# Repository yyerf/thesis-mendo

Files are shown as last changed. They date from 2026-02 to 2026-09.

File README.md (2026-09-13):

# Mendo

Mendo is a multilingual, knowledge-based expert system for OTC consultation and
medicine vending. It combines deterministic English/Tagalog/Cebuano phrase and
safety rules with the pretrained
`sentence-transformers/paraphrase-multilingual-MiniLM-L12-v2` embedding model.
MiniLM cosine similarity supports phrase interpretation; it is not a trained
clinical classifier and its scores are not probabilities.

## Run locally

Python 3.10+ is recommended.

```bash
python3 -m venv .venv
source .venv/bin/activate
pip install -r requirements.txt
python3 app.py
```

Open `http://localhost:5000`. On first run, Mendo creates
`data/mendo_pos.db`, applies additive migrations, seeds the inventory, and
downloads MiniLM if it is not already cached. The runtime database, journals,
application logs, and raw consultation logs are intentionally ignored by Git.

The seeded administrator is for first-run development only:

- Username: `admin`
- Password: `mendo2026`

Change the password immediately in any shared or deployed environment, and set
`MENDO_SECRET_KEY` to a stable secret.

## Hardware integration status

The current build is intentionally **payment-only**. The tested Allan D2 coin
path and TB74 D3 bill path are integrated with the Cashier and kiosk checkout
screens. A successful payment creates one receipt and deducts reserved stock
exactly once. Medicine motors are compile-time disabled: no paid checkout can
send a servo/rotor command in this phase.

The real controller runs at 115200 baud through the dedicated hardware daemon.
Simulator cash remains visibly labelled for software-only tests. This is a
prototype test gate, not production authorization; wiring, voltage, enclosure,
cashbox, restart-replay, and long-run acceptance evidence still require
completion. See the [hardware guide](hardware/README.md) and
[CHECKPOINT.md](CHECKPOINT.md) before connecting an Arduino.

## Ten-slot medicine catalog

Production recommendations, POS inventory, checkout, and benchmarks use one
versioned hardware catalog:
`mendo-hardware-catalog-v1-2026-07`. The formulation-level JSON remains the
reference source, but runtime loading selects exactly these ten physical items:

| Slot | Medicine | Runtime category | Form | Minimum age |
|---:|---|---|---|---:|
| 1 | Advil | Pain & Inflammation | Tablet | 12 |
| 2 | Bioflu | Cold & Flu | Tablet | 12 |
| 3 | Biogesic | Pain & Fever | Tablet | 12 |
| 4 | Cetirizine | Allergy | Tablet | 6 |
| 5 | Solmux | Cough with Phlegm / Productive Cough | Capsule | 12 |
| 6 | Tuseran | Dry Cough | Tablet | 12 |
| 7 | Symdex | Cold & Cough | Tablet | 6 |
| 8 | Neozep | Cold | Tablet | 6 |
| 9 | Loperamide | Anti-diarrhea | Tablet | 6 |
| 10 | Erceflora | Probiotic (Adjunct for Diarrhea) | Oral Suspension | All ages |

Startup migrations rename older aliases without changing inventory IDs, assign
hardware slots, and mark products outside the catalog inactive. Historical
transactions and stock movements are never deleted. Erceflora is treated only
as an adjunct; food-poisoning guidance still requires oral rehydration and
excludes loperamide.

## Consultation and audit flow

1. The participant accepts or declines multilingual research consent.
2. Dictionary rules record matched, negated, and safety-suppressed evidence.
3. MiniLM records its model id, anchors, threshold, and cosine similarities.
4. Expert rules resolve symptom labels, red flags, severity, duration,
   clarification, age, headache illustration, and recommendation filtering.
5. Consented consultations are stored as session timelines for independent
   domain-expert review.
6. An administrator adjudicates disagreements into a final gold annotation.
7. Only consented and adjudicated records enter research exports or field
   validation metrics. Nothing automatically retrains production.

Declining consent does not block consultation. Raw health text is not persisted;
only an anonymous aggregate operational counter is incremented. The 507
pre-consent interactions retained during merge recovery are marked
legacy/unconsented and excluded from research exports and field metrics.

## Evaluation terminology

- **Synthetic technical benchmark**: researcher/LLM-created regression cases in
  `testing/benchmark/testing.csv`. This is technical evidence, not clinical
  field validation.
- **Domain-expert field validation**: independently reviewed, consented
  consultations with administrator-adjudicated gold labels.
- **Per-case precision, recall, F1, and exact match**: computed only after
  adjudication.
- **Micro F1**: pools label decisions across all eligible cases.
- **Macro F1**: averages performance across labels.
- **Cohen’s kappa**: shown only when at least two reviewers share reviewed
  cases; otherwise the interface reports “insufficient reviewers.”
- **Clinical appropriateness**: the proportion of adjudicated recommendation
  judgments marked appropriate among appropriate/inappropriate judgments.

Run verification:

```bash
python3 -m unittest discover -s testing -p 'test_*.py' -v
python3 testing/test_algorithm.py
```

The benchmark script uses the same `predict_symptoms` service as
`/consult/api/analyze`, reports both raw-input and guided-clarification metrics,
and writes the single tracked manifest at
`testing/benchmark/results/current.json`. Timestamped HTML/CSV runs are ignored.

## Repository map

- `mendo_core/prediction_pipeline.py` — deployed, versioned prediction service
- `mendo_core/medicine_catalog.py` — canonical hardware-slot allowlist and aliases
- `mendo_core/interaction_logger.py` — consent, audit, reviews, adjudication,
  metrics, and de-identified exports
- `pos/routes_consultation.py` — consultation APIs
- `pos/routes_admin.py` — restricted clinical audit APIs
- `web/templates/pos/logs.html` — session-oriented reviewer interface
- `testing/benchmark/results/current.json` — current synthetic benchmark manifest
- `docs/thesis/current/` — canonical thesis and synchronized comments document
- `docs/thesis/archive/` — prior DOCX/PDF revisions retained in history
- `docs/research/` — research audits and diagrams
- `docs/defense/` — defense notes and presentation material

The ignored `_For-Mendo/` five-brand SVM prototype is not a production
dependency and is not imported by the application.

See [docs/README.md](docs/README.md) for the document index.

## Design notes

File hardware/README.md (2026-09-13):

# MendoVendo hardware guide

Status: **payment-only POS integration enabled for the measured D2/D3 pulse paths; medicine motors disabled**

The controller now carries the same D2 coin and D3 TB74 timing filters used by
the successful bench sketch. The host maps validated pulses, binds them to one
active payment session, persists them before ACK, and retains every queued
event in a burst. When the amount due is reached, inventory and the receipt are
committed atomically. `DISPENSE_ONE` remains rejected at the firmware boundary,
and PCA9685 OE is held HIGH (disabled).

This enables the requested supervised POS payment test. It does not establish
production readiness: keep medicine motors disconnected, keep the collection
box supervised, and retain the simulator label as the software-only fallback.
The supplied legacy sketches remain under [`references/legacy/`](references/legacy/)
and are not the integrated controller.

## Run a payment-only test

1. Open `hardware/firmware/mendo_controller/mendo_controller.ino` in Arduino
   IDE, select Arduino Uno, and upload it. Close Serial Monitor afterward; the
   daemon needs exclusive access at **115200 baud**.
2. Start the hardware daemon (replace `/dev/ttyACM0` if the Uno has another
   stable path):

   ```bash
   MENDO_HARDWARE_MODE=real \
   MENDO_HARDWARE_SOCKET=/tmp/mendo-hardware.sock \
   MENDO_SERIAL_DEVICE=/dev/ttyACM0 \
   ./.venv/bin/python -m hardware.daemon_main
   ```

3. In a second terminal, start the POS against the same socket:

   ```bash
   MENDO_HARDWARE_MODE=real \
   MENDO_HARDWARE_SOCKET=/tmp/mendo-hardware.sock \
   ./.venv/bin/python app.py
   ```

4. Open `/shop`, add medicine, select **Start Cash Payment**, and insert cash.
   The live dialog shows due, inserted, and remaining values. On success, verify
   `/admin/inventory`, the receipt, and stock logs. No motor job should exist.

## Reference files

Tracked copies and provenance are listed in
[`hardware/references/README.md`](references/README.md). The original supplied
files remain at the repository root while this integration is being audited.

The TB-to-Uno bench wiring is documented in the
[editable wiring diagram](tb-arduino-uno-wiring.svg) and its
[connection guide](tb-arduino-uno-wiring.md). Neither authorizes physical
power-up; the Phase-0 identity, polarity, voltage, and pulse-evidence gate
must be cleared first.

## Locked hardware mapping

| Arduino connection | Function |
| --- | --- |
| D0/D1 | USB serial only; no peripherals |
| D2 / INT0 | conditioned Allan coin pulse input |
| D3 / INT1 | conditioned TB METER pulse input |
| D4 | TB inhibit transistor control |
| D5 | fail-off coin-acceptor power relay/load switch |
| D6 | reserved for future shared chute sensor |
| D7 | PCA9685 active-low OE safety control |
| D8 | reserved enclosure/interlock input |
| A4/A5 | PCA9685 SDA/SCL |
| PCA channels 0–9 | hardware slots 1–10 |

Uno and Mega builds must share one source tree. Board selection is a
compile-time target detail only; slot numbering, protocol frames, and database
mapping do not change.

## Power and safety gate

- Power the Arduino from host USB. Never put the acceptor’s 12 V rail on an
  Arduino input.
- Use a separately fused regulated 12 V supply for the TB and Allan devices.
  The TB guide states 12 V DC ±10%, with up to 1.2 A maximum operation.
- Use the external fused 5 V servo supply for the PCA9685 servo rail. Never
  power an MG996R from the Uno 5 V pin. Only one servo may be active at a time.
- Tie Arduino ground, PCA9685 logic ground, and servo-supply ground together
  at the documented logic boundary; keep the 12 V cash-device side isolated
  through the optocoupler/load-control interfaces.
- A hardware pull-up on PCA9685 OE must leave outputs disabled during reset,
  boot, serial loss, and firmware failure.
- Fit a master disconnect, branch fuses sized from measured current, terminal
  blocks, strain relief, and a locked collection enclosure.
- Before attaching the Uno, perform continuity and voltage tests. Every
  conditioned Arduino-side signal must measure 0–5 V in all expected states.

## TB bill acceptor bench wiring

The supplied guide documents WEL-R7U02 as follows. Verify every conductor with
continuity; do not trust color alone.

| Harness color | Function |
| --- | --- |
| Red | +12 V DC |
| Orange | 12 V ground |
| Blue | METER+ |
| Purple | METER- |
| Yellow | INHIBIT+ |
| Green | INHIBIT- |

Use the manual’s isolated customer-side pulse circuit: 4.7 kΩ pull-up to
Arduino 5 V, METER+ to D3, and METER- to Arduino logic ground. Drive the
inhibit pair through the documented NPN interface with a base resistor and
hardware pull-down. Select and prove a polarity where boot, reset, missing
heartbeat, disconnected USB, and daemon failure inhibit the acceptor.

The exact TB model (TB74/TB77 variant), PHP firmware label, DIP banks, currency
sheet, pulse protocol, and pulse counts are **not yet recorded**. Do not copy
settings from a TP-series Philippine sheet. Record twenty consecutive correct
trials for each enabled ₱20/₱50/₱100 denomination and rejection trials for
₱200/₱500/₱1000 before enabling cash.

## Allan coin acceptor bench calibration

Use a 12 V-rated optocoupler input module. The unknown-voltage COIN wire must
not connect directly to D2. The optocoupler’s 5 V-side collector connects to
D2 with an external pull-up. Control acceptor power through the fail-off relay
or rated high-side load switch on D5 so an inactive order cannot swallow a
coin.

The selected six programs are:

| Program | Coin sample | H | P | F |
| --- | --- | ---: | ---: | ---: |
| 1 | old/current ₱1 | 20 | 1 | 8 |
| 2 | other ₱1 variant | 20 | 1 | 8 |
| 3 | old/current ₱5 | 20 | 5 | 8 |
| 4 | other ₱5 variant | 20 | 5 | 8 |
| 5 | old/current ₱10 | 20 | 10 | 8 |
| 6 | other ₱10 variant | 20 | 10 | 8 |

Use actual circulating coins in acceptable condition. Start at medium pulse
speed. For each accepted sample, capture pulse width, inter-pulse gap, total
train duration, idle level, and the conditioned D2 voltage. Firmware constants
must be derived from those captures. Unknown trains disable both acceptors and
route the order to manual review.

## Servo and rotor safety

PCA channels 0–9 map to slots 1–10. Each persisted profile must include
`position_a_us`, `position_b_us`, travel time, B dwell, return settle, cooldown,
and profile version. Pulse widths must be calibrated and range-checked; do not
assume 0°/180° endpoints. A `DISPENSE_ONE` job executes A → B → A, disables
the channel’s PWM, and reports only `dispensed_done_unverified` until the
future shared chute sensor is installed.

Phase 4 evidence must include 100 unloaded cycles and 20 loaded trials per
slot, with current draw, voltage droop, resets, jams, and wear recorded. A
successful servo acknowledgment is not evidence that medicine physically
reached the customer.

## Phase 0 evidence worksheet

Complete this table from the physical bench and attach photos or capture files
under `hardware/evidence/` (do not commit secrets or customer data).

| Evidence | Result | File/photo/capture |
| --- | --- | --- |
| TB exact model and variant | TB74-PH60Ni (label TB7441123 / 10PH6003 / B444) | operator-reported |
| TB PHP firmware label | PH6 — ₱20/50/100/200/500/1000 | vendor sheets in `references/vendor-dip-sheets/` |
| TB harness continuity | **pending** | pending |
| TB DIP banks and inhibit polarity | Pulse mode, 1 pulse/₱10, Fast, inhibit Active High; SW6+SW7 enable ₱20/₱50/₱100 | `docs/architecture/tb74-pulse-protocol-analysis.md` §1b |
| TB ₱20 pulse count/width/gap | **2 pulses**, 50 ms LOW, 151 ms period | 2026-08-03 23:23:16 capture |
| TB ₱50 pulse count/width/gap | **5 pulses**, 50 ms LOW, 150 ms period | 2026-08-03 23:23:21 capture |
| TB ₱100 pulse count/width/gap | **10 pulses**, 50 ms LOW, 150 ms period | 2026-08-03 23:23:24 capture |
| Higher-bill rejection | **pending** — ₱200/₱500/₱1000 disabled at DIP, not yet trialled | pending |
| Rejected-note zero-credit | 6 rejections, 23,064 raw edges, ₱0 credited | 2026-08-03 23:23 capture |
| Allan coin pulse captures | **pending** | pending |
| Arduino-side D2/D3 levels | **pending** | pending |
| 12 V and servo-rail measurements | **pending** | pending |
| Hardware photos | **pending** | pending |

Until every required row has evidence, the production gate remains closed.

## Software-only integration

The durable workflow lives in `pos/order_service.py`. It reserves stock using
`stock_quantity - reserved_quantity`, records integer-centavo payment events
exactly once, creates one immutable dispense job per unit, and projects one
legacy receipt only after every actuator job is acknowledged as
`done_unverified`. A successful controller motion is never presented as proof
that medicine reached the chute.

After a Flask restart, polling a paid order resumes the durable dispatcher. It
queries any `started` job by immutable controller ID before sending another
command. Only a controller-negative `known=0` answer can release a job for a
staff retry; a missing or ambiguous answer remains manual review.

The hardware boundary is split into three processes/roles:

- `hardware.simulator.SimulatedHardware` is the deterministic development
  backend. Its status always says `mode=simulator` and
  `physical_evidence_required=true`.
- `hardware.daemon` owns the Unix socket and, in real deployments, the only
  serial descriptor. Flask workers use `UnixHardwareClient`; they never open a
  TTY. The sample systemd unit runs the daemon as `mendo-hardware:dialout`.
- `hardware.real_backend.SerialHardwareBackend` performs the bounded CRC
  handshake and heartbeat when the daemon is explicitly started in real mode.
  The firmware and service still require the physical-evidence/configuration
  gate to be cleared before cash can start.

Development commands:

```text
./.venv/bin/python -m pytest -q
MENDO_HARDWARE_MODE=simulator ./.venv/bin/python -m hardware.daemon_main
```

Do not set `MENDO_HARDWARE_MODE=real` until the Phase-0 worksheet is complete
and the R1–R4 remediation checkpoints have been approved. The current daemon
and firmware sources are not a release authorization for powered hardware.
The sample udev rule grants access to the dedicated daemon identity through
`dialout`; it does not recommend `chmod 666`.

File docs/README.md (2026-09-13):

# Thesis and research document index

## Current thesis

- `thesis/current/Latest-July-26-Thesis-Paper.docx` — canonical thesis paper
- `thesis/current/Thesis (Comments_Suggestions) - Synced.docx` — synchronized
  routing/comments companion

The paper files were reorganized only. Their prose was not silently rewritten.

## Archive

`thesis/archive/` contains previous DOCX/PDF revisions. Git history is retained,
but these files are not the current thesis source.

## Research material

- `architecture/cash-order-integration.md` — current durable order, hardware
  daemon, accounting, and recovery boundary
- `research/audits/` — architecture reviews, benchmark verification,
  methodology notes, and implementation proposals
- `research/diagrams/` — conceptual-framework HTML diagrams
- `../experiments/` — reproducible classifier/retrieval experiment code

Historical analyses may describe superseded behavior. The deployed architecture
and current terminology are defined by the repository README, the versioned
prediction trace, and the current benchmark manifest.

## Defense material

`defense/` contains checklists, mock-defense questions, demo notes, prompts, and
presentation drafts.

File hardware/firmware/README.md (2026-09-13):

# Uno/Mega controller firmware

`mendo_controller.ino` is the payment-only controller for the tested D2 coin
and D3 TB74 pulse paths. It is a single Arduino IDE sketch and also shares Uno
and Mega build definitions through `platformio.ini`:

```text
pio run -d hardware/firmware -e uno
pio run -d hardware/firmware -e mega
```

The cash gate is enabled from the completed pulse trials. Firmware reports
validated counts only; the Python host owns the peso mapping. The Uno build is
verified at 10,526 bytes flash and 1,407 bytes globals (641 bytes free), and frame transmission
streams its CRC instead of allocating a second large buffer on the stack.

Medicine motion is a separate gate and remains disabled. `DISPENSE_ONE` is
always rejected, PCA9685 OE is HIGH during boot/fail-safe/payment, and the
placeholder motion profiles must not be treated as calibration. Keep servos
disconnected during this phase. Cash-event replay after a daemon/controller
restart still needs a supervised fault test before production use.

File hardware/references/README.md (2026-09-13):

# Hardware reference provenance

These files are tracked copies of the user-supplied reference assets. The
original files remain at the repository root so their provenance is not lost.

| Tracked asset | Source asset | SHA-256 |
| --- | --- | --- |
| `allan-coinslot-calibration.pdf` | `allan coinslot calibration.pdf` | `f61b90333173e95069c2289ed1c668c82da0534886f46532962bb72f7905f08b` |
| `tb-series-installation-guide.pdf` | `tb_series.pdf` | `e76750a452e1b8256df684c881cd9940aa46bf6f3ee66b8e4ce60f6dc296d407` |
| `rotor_9pocket_35x20_recommended_clearance.stl` | `rotor_9pocket_35x20_recommended_clearance.stl` | `00e499be5a23a621b7a459fb6b675dc161f6a2a7e32c4f136401d9f087d7f9a8` |

The TB PDF is a generic TB-Series installation guide. It is not the missing
Philippine currency/DIP sheet and must not be used to infer PHP bill settings.

## Vendor DIP sheets

`vendor-dip-sheets/` holds manufacturer DIP-switch sheets retrieved for sibling
currency builds, including a genuine TOPVME **TB74** sheet on the same 10-way +
4-way bank layout as our unit, and two **PHP6** currency sheets. See
[`vendor-dip-sheets/README.md`](vendor-dip-sheets/README.md) for provenance and
the analysis in
[`docs/architecture/tb74-pulse-protocol-analysis.md`](../../docs/architecture/tb74-pulse-protocol-analysis.md).
These are still not the Philippine sheet for our exact unit; they narrow the
Phase-0 bench trial, they do not replace it.

## Legacy evidence

`legacy/Bill_Acceptor.ino` is the supplied V1 bill sketch. It is retained for
audit/provenance only and is not an approved controller source. Its 1-pulse =
₱10 mapping is an unverified starting hypothesis; do not flash it or use its
timing constants as calibration evidence.

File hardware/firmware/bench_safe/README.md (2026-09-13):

# USB-only bench diagnostic

`bench_safe.ino` is a temporary diagnostic image for board identification and
serial testing while the cash acceptors, PCA9685, and servos are disconnected.
It does not capture cash, drive the TB inhibit pair, access I2C, or move a
servo. It holds coin power off and PCA9685 OE high (disabled).

This is not the integrated controller and is not a cash-acceptance test.

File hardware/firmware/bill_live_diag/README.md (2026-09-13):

# Live bench diagnostics

Two read-only Arduino Uno sketches. Neither drives inhibit, coin power,
PCA9685 OE, or a servo. Neither can credit an order. They are bench
instruments; the Phase-0 gate in `hardware/README.md` still governs.

## `bill_live_diag` — is this a credit pulse or noise?

Watches **both** D2/INT0 and D3/INT1, so it works regardless of which pin
METER+ landed on. For every burst of line activity it prints raw edge count
next to clean pulse count:

- **raw edges** — unfiltered interrupt count, i.e. the noise floor
- **clean pulses** — survivors of a 20 ms glitch filter, i.e. real credit

The gap between those two numbers is the whole diagnosis. `raw=4000,
clean=0` means the line is busy but nothing was ever paid.

It also reports LOW width, pulse period, whether the timing matches TB74 Fast
(50/100) or Slow (50/300), and maps clean pulse counts to pesos at the
documented 1 pulse = ₱10 scaling:

| pulses | 2 | 5 | 10 | 20 | 50 | 100 |
| --- | --- | --- | --- | --- | --- | --- |
| value | ₱20 | ₱50 | ₱100 | ₱200 | ₱500 | ₱1000 |

Any interval under 80 ms is counted separately as `sub-80ms events` — the
fastest credit pulse in this whole device family is 80 ms, so those are
provably not payment.

## `line_check` — what is physically attached to this pin?

Samples D2 and D3 with the internal pull-up ON and OFF and reports duty
cycle, transition count and rate. That separates:

| Result | Meaning |
| --- | --- |
| `HELD LOW` | low-impedance path to GND — the pull-up cannot lift it. An idle METER+ reads HIGH, so this pin is **not** METER+ |
| `HIGH and quiet` | idle METER+ (correct), or an open pin — insert a note to tell them apart |
| `FLOATING` | nothing driving it |
| `OSCILLATING` | active noise source, unusable as-is |

## Running them

```bash
# build + flash
arduino --upload --board arduino:avr:uno --port /dev/ttyACM0 \
  hardware/firmware/bill_live_diag/bill_live_diag.ino

# watch (Ctrl-] to quit)
python3 -m serial.tools.miniterm /dev/ttyACM0 115200
```

Serial is **115200**. If you use the Arduino IDE's Serial Monitor instead,
set the baud rate to match or you will see garbage.

`USE_INTERNAL_PULLUP` at the top of `bill_live_diag.ino` defaults to `1` so
the sketch runs on the existing wiring. Set it to `0` once the external
4.7 kΩ pull-up to Uno 5 V is fitted — that is the value the TB manual's pulse
interface actually specifies (printed page 13 / PDF page 16).

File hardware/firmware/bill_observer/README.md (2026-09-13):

# TB bill-only observer

`bill_observer.ino` is an observe-only Arduino Uno sketch for the TB
WEL-R7U02 METER output. It captures `CHANGE` edges on D3/INT1 and prints raw
pulse count, every edge timestamp, pulse width, inter-pulse gap, train
duration, and the unverified V1 candidate mapping:

- 2 pulses → candidate ₱20.00
- 5 pulses → candidate ₱50.00
- 10 pulses → candidate ₱100.00

The mapping and 250 ms train gap are hypotheses only. The sketch never credits
an order, drives D4/TB inhibit, powers a coin acceptor, accesses the PCA9685,
or moves a servo.

Serial is 115200 baud. Send `ARM` before a pulse trial; use `STATUS`, `HELP`,
or `DISARM` as needed. Keep the TB inhibit pair disconnected from the Uno
until the exact TB PHP/DIP polarity has been measured. This is not a
production cash controller.

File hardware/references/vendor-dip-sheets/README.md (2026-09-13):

# Vendor DIP-switch sheets (external evidence)

Downloaded 2026-08-03 while reverse-engineering the TB74-PH6 pulse interface.
These are **manufacturer documents for sibling currency builds**, not the
missing Philippine sheet for our exact unit. They are strong structural
evidence and they agree with each other, but the Phase-0 bench trial is still
what promotes any value here to "measured".

| File | Source URL | What it establishes |
| --- | --- | --- |
| `TB74-DipSetting-Mexico-MXP6-20-1K-RS232-104U.pdf` | `topvme.com/index.php/files/330/Currencies-accepted-and-DipSetting/417/` | **Primary.** Genuine TOPVME **TB74** sheet. MXP6 = 20/50/100/200/500/1000 — the same six-bill structure as PHP6 — on the same **10-way + 4-way** bank layout as our unit. |
| `ICT-V7P-PHP6-Pulse-MDB-ICT104V-ICT104U.pdf` | `icteurope.de/en/files/V7P/` | Genuine **PHP6** currency set: confirms ₱20/50/100/200/500/1000 and the `1 pulse / PHP 10` base scaling. 8+4 bank variant. |
| `ICT-TAO-A.V-PHP6-Pulse-ICT-MDB.pdf` | `ictgroup.net.cn/files/tao/` | Second independent **PHP6** sheet; same denominations and same ₱10 pulse base. |
| `ICT-TP70-P5-MYR7-Pulse.pdf` | `ictgroup.net.cn/files/TP70/` | Independent **10-way + 4-way** layout confirming the SW1-3 / SW4 / SW5 / SW6-10 role split. |

## Bank-layout families

Two families exist in this device class. Do not mix their polarities.

- **10 + 4 banks** (TB74, TP70/P5, L70/P5) — SW1-3 pulse scaling, SW4 speed,
  SW5 inhibit level, SW6-10 denominations, **ON = ACCEPT**.
- **8 + 4 banks** (ICT TAO-A.V, V7P) — SW1-5 denominations with
  **ON = REJECT**, SW7 harness, SW8 inhibit level; scaling/timing live on the
  4-way bank.

Our unit has CTS195-10 (10-way) + CTS208-4 (4-way), so it is the **10 + 4**
family and **ON = ACCEPT**.

## Rejected source

`industrialmonitordirect.com/blogs/knowledgebase/tb74-bill-acceptor-arduino-wiring-and-pulse-output-configuration`
claims the TB74 has a single 8-position bank with switch 7 = pulse width and
switch 8 = output polarity. That contradicts both the physical hardware
(10-way + 4-way) and the manufacturer sheet above. Treat that page as
unreliable; do not cite it.

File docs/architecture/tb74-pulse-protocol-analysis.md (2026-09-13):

# TB74-PH6 bill validator — protocol reverse-engineering analysis

Date: 2026-08-03. Status: **desk analysis complete, bench verification pending.**

This answers the V1 reverse-engineering brief. It does not authorize powered
cash. The `hardware/README.md` Phase-0 worksheet still governs.

---

## 0. Executive summary

Three findings, in order of importance.

1. **The protocol is Pulse, not RS232.** Settled by the 4-way DIP bank, which
   is already on its correct factory default. Hypothesis 1 in the brief is
   dead.
2. **The DIP switches are wrong. ₱50 and ₱100 are currently set to REJECT.**
   Only ₱20 is enabled. Two switches need to move: **SW7 and SW8 on the 10-way
   bank → ON.**
3. **The ₱50 note was never accepted, so no credit pulse was ever emitted.**
   Every pulse count recorded so far (122, 79, 30, 19, 1, 77/26/3) is motor and
   EMI noise from the acceptor pulling the note in, scanning it, and returning
   it. The timing proves this independently of the DIP finding.

---

## 1. The timing proof — why every measurement so far is noise

The TB74 pulse output has exactly two speed settings, selected by SW4 of the
10-way bank:

| SW4 | Mode | LOW (active) | HIGH (idle) | Falling-edge period |
| --- | --- | ---: | ---: | ---: |
| ON | Fast | 50 ms | 100 ms | **150 ms** |
| OFF | Slow (default) | 50 ms | 300 ms | **350 ms** |

The sibling ICT PHP6 sheets offer at most four options, the fastest being
`30 ms LO / 50 ms HI` = **80 ms period**. A TB74 Taiwan build uses 75/75 and
150/150.

**Across every documented configuration of this device class, the shortest
possible interval between two credit pulses is 80 ms. Our unit, on SW4=ON, is
150 ms.**

The brief records measured gaps of **~8 ms, ~10 ms, ~20 ms**.

That is one to two orders of magnitude too fast. No DIP setting, no currency
build, and no firmware revision of this acceptor emits credit pulses at that
rate. Therefore **none of the recorded edges were credit pulses.** The
observation that activity appears only while the transport motor runs, and
stops when idle, is consistent with brushed-motor commutation noise coupling
into a high-impedance input.

This also explains the "results varied dramatically" problem. The counts were
never measuring the device — each diagnostic sketch was measuring its own
debounce constant against a noise floor. A sketch with no debounce reported
122; one with a 50 ms debounce collapsed the same burst to 1.

Two contributing electrical factors:

- The input is on `INPUT_PULLUP` (internal, ~20–50 kΩ). The manual's pulse
  interface (printed page 13 / PDF page 16) is an opto-isolated open-collector
  **Credit O/P** and specifies an external **4.7 kΩ** pull-up. At 20–50 kΩ the
  node is 4–10× more susceptible to injected noise and has slow edges.
- Slow edges through a non-Schmitt AVR interrupt pin can retrigger. This is
  secondary here — it produces sub-millisecond bursts, not 8–20 ms ones — but
  it compounds the problem.

---

## 1a. Bench measurement, 2026-08-03 — the wiring is wrong upstream of the DIPs

Measured live on the connected Uno with `hardware/firmware/line_check`.
No note inserted, machine idle:

| Pin | Pull-up ON | Pull-up OFF | Reading |
| --- | --- | --- | --- |
| **D2 / INT0** | **0 % high**, ~14 glitches/400 ms, min run 8 µs | **0 % high, 0 transitions** | **HELD LOW** |
| **D3 / INT1** | 100 % high, 0 transitions | 100 % high, 0 transitions | HIGH and quiet |

`bill_live_diag` on the same wiring reported **~8,000 raw edges per second on
D2, continuously, with no note anywhere near the machine**, and `clean pulses
= 0` on every single burst. D3 never triggered at all.

**D2 cannot be METER+.** The TB74 pulse output is an opto-isolated
open-collector Credit O/P: idle means the transistor is off, the collector is
open, and a pull-up must lift the node HIGH. The Uno's internal pull-up cannot
lift D2 at all, and with the pull-up removed the pin is flat LOW with zero
transitions. That is a low-impedance path to ground — a **ground wire on the
wrong pin**, not a credit output.

This sits upstream of the DIP finding and explains the entire measurement
history in the brief: the counts were never wrong readings of the credit
output, they were readings of something that was never the credit output.

D3 reading a steady HIGH is consistent with either a correctly-landed idle
METER+ or an open pin — 400 ms is not long enough for AVR pin capacitance to
decay, so the two cannot be separated without inserting a note. Note that D3
is also what `hardware/README.md` locks METER+ to.

**Resolve before re-testing:** confirm by continuity which harness conductor
is on D2 and which is on D3. TB pin 7 BLUE (METER+) belongs on **D3**; TB pin 8
PURPLE (METER-) belongs on **Arduino GND**, not on an input pin.

## 1b. CONFIRMED — first successful credit read, 2026-08-03 23:09:16

After moving METER+ to D3 and fitting the external 4.7 kΩ pull-up, a ₱50 note
was inserted and **kept (stacked)**. Captured on D3/INT1:

```
channel        : D3 / INT1
raw edges      : 2317   (unfiltered)
clean pulses   : 5      (real credit)
LOW width      : 50 / 50 / 50    ms  (min/avg/max)
pulse period   : 150 / 150 / 151 ms  (min/avg/max)
VERDICT        : CREDIT PULSE TRAIN (timing valid)
timing profile : TB74 FAST (50/100, SW4=ON)
MONEY          : PHP 50.00
```

Every predicted value reproduced exactly:

| Predicted | Measured | |
| --- | --- | --- |
| Pulse protocol, not RS232 | pulses on METER, no serial | ✅ |
| LOW width 50 ms | 50 / 50 / 50 ms, zero jitter | ✅ |
| Period 150 ms (Fast, SW4=ON) | 150 / 150 / 151 ms | ✅ |
| 1 pulse = ₱10 | ₱50 note → 5 pulses | ✅ |
| METER+ belongs on D3 | clean train on D3 | ✅ |

The `raw edges = 2317` against `clean pulses = 5` in the same window is the
other half of the result: transport-motor noise **is** present on the line and
coexists with the credit train. A 20 ms glitch filter separates them cleanly.
Any firmware that counts raw edges will massively over-credit.

Supporting evidence from the same session: the legacy `Bill_Acceptor.ino` was
left running on the mis-wired input for ~13 minutes and accumulated
**₱16,130 of credit that was never inserted**. That is the concrete
demonstration of why the V1 sketch is unsafe as a cash controller.

Also observed: with `USE_INTERNAL_PULLUP 0`, the unconnected D2 floated and
reported a phantom train at `period 150/150/151 ms` — identical to the real D3
train — at the same instant. That is capacitive crosstalk from the adjacent
pin, not a signal. Unwatched interrupt pins must be tied off with
`INPUT_PULLUP`, which `bill_ide_paste` now does.

### Full denomination set, 2026-08-03 23:23 (D2 tied off, totals trustworthy)

| Time | Note | Clean pulses | LOW width | Period | Read as |
| --- | --- | ---: | --- | --- | --- |
| 23:23:16 | ₱20 | **2** | 50/50/51 ms | 151/151/151 ms | PHP 20.00 |
| 23:23:21 | ₱50 | **5** | 50/50/51 ms | 150/150/151 ms | PHP 50.00 |
| 23:23:24 | ₱100 | **10** | 50/50/51 ms | 150/150/151 ms | PHP 100.00 |

**Session total ₱170.00 = ₱20 + ₱50 + ₱100, exact.** Zero phantom credits.
2/5/10 pulses at 1 pulse/₱10 across the whole enabled set, all at 50 ms LOW
and a 150 ms period.

### Noise rejection under load — the safety-critical result

The same run included six failed/rejected insertion attempts before the ₱20
succeeded. Raw versus clean, every event:

| Event | Raw edges | Clean pulses | Credited |
| --- | ---: | ---: | --- |
| 6 rejected attempts | 792, 1704, 2749, 5146, 5969, 6704 | **0 each** | ₱0 ✅ |
| ₱20 accepted | 4,924 | 2 | ₱20 ✅ |
| ₱50 accepted | **12,871** | 5 | ₱50 ✅ |
| ₱100 accepted | 3,263 | 10 | ₱100 ✅ |

Two properties matter here and both hold:

1. **No false credit on rejection.** 23,064 raw edges across six rejected
   attempts produced ₱0. A rejected note never pays.
2. **Correct extraction under the worst noise.** The ₱50 read carried a
   2574:1 noise-to-signal ratio and still yielded exactly 5 pulses. Naive
   raw-edge counting at ₱10/pulse would have credited **₱128,710** for that
   single ₱50 note.

This is the empirical justification for the 20 ms glitch filter and for
treating raw interrupt counts as unusable in any cash path.

### Polymer banknotes are rejected — acceptor firmware limitation, 2026-08-03

The new **polymer ₱100 is consistently rejected** while paper ₱100 reads
correctly at 10 pulses. This is not a wiring, DIP, or software fault, and no
change on our side can fix it.

Bangko Sentral ng Pilipinas released the polymer ₱500/₱100/₱50 (First
Philippine Polymer Banknote Series) on **23 December 2024**, nationwide from
January 2025. The polymer ₱1000 preceded it in 2022. Our unit's currency
dataset is labelled `10PH6003` and the supplied TB-Series guide is dated
May 2022 — the templates predate the polymer series by roughly two years.

A validator authenticates against stored optical/UV/IR templates. Polymer
substrate has entirely different signatures and thickness from abaca paper, so
an older dataset cannot match it. DIP switches only enable or disable
denominations that already exist in the dataset; they cannot add one.

**Fix:** reload the currency dataset with the G-BOX programmer. The TB-Series
guide §5-3 ("Software download") directs users to the local agent or
`service@topvme.com.tw`. Request a PH6 dataset that includes the polymer
series, then re-run the Phase-0 trials for every denomination.

**Until then the behaviour is safe, not silently wrong.** A polymer note is
drawn in, examined, and returned; the acceptor emits no credit pulses and the
filter reports `clean=0`. The customer keeps their money and receives nothing.
That is the correct failure direction — but it is an acceptance-rate and
usability limitation that grows as polymer notes displace paper, and it must
be declared rather than hidden. Paper notes remain legal tender and still
circulate, so the kiosk is usable in the interim.

### Allan coin acceptor — misclassification observed, 2026-08-04

After calibration the coin geometry is consistent and the linear model holds:
**1 pulse = ₱1** at every denomination, ~70 ms LOW, ~170 ms period.

| Coin | Pulses | Samples |
| --- | ---: | ---: |
| ₱1 | 1 | 6 |
| ₱5 | 5 | 3 |
| ₱10 | 10 | 1 |
| ₱20 | 20 | 1 |

**But two ₱10 coins dropped in one session produced 1 pulse and 10 pulses —
₱11 credited for ₱20 inserted.** The 1-pulse event (raw 893, span 472 ms,
LOW 69 ms) is byte-for-byte the signature of a genuine ₱1 drop, and its span
matches a single clean pulse rather than a truncated train. The acceptor
emitted exactly one pulse: it **classified a ₱10 coin as a ₱1**.

This is a coin-recognition failure inside the Allan unit. No firmware or host
logic can detect it, because both 1 and 10 are legitimate pulse counts. The
pulse train is perfectly formed; only its *value* is wrong.

**Why it is worse than it looks.** The error is symmetric. A ₱10 read as ₱1
shortchanges the customer by ₱9; a ₱1 read as ₱10 shortchanges the operator by
the same amount. The linear coin model cannot reject either, and a strict
lookup table would not help — 1 and 10 are both valid entries.

Contrast with bills: the TB74 carries a manufacturer currency dataset and
encodes denomination in the pulse count, so a wrong count is detectable and
gets rejected. Coin discrimination is only as good as the samples taught into
the unit, and the host has no way to audit it.

**Probable cause.** Philippine coins exist in old and NGC (2018-) variants
with different diameters and alloys. Programming one slot per denomination
(E=4) leaves no room to teach both variants, so a coin of the untaught variety
can fall into a neighbouring program's tolerance band. The original six-program
plan in `hardware/README.md` (old/new for ₱1/₱5/₱10) exists precisely to avoid
this; trading those variant slots for a fourth denomination is what opened the
gap.

**Remediation, in order:**

1. Re-teach with `H = 20` samples per program using a deliberate mix of old
   and NGC coins of that denomination.
2. Prefer `E = 6` with variant coverage over `E = 4` with an extra
   denomination, unless ₱20 acceptance is worth more than accuracy.
3. Tighten `F` and re-test; record the direction that helps, since the
   supplied sheet does not state it.
4. Measure a **misclassification rate**: 20 drops per denomination, recording
   the pulse count for each. Anything above zero is a money defect.

**Open design question.** The kiosk sells ~₱9.50 items and already accepts
₱20/₱50/₱100 notes reliably. If the misclassification rate cannot be driven to
zero, running bills-only is a defensible configuration: it removes an
unauditable money error at the cost of some convenience. Coin credit must stay
gated until step 4 produces a clean result.

### Denomination switch assignment — two candidates, unresolved

The only 10-way change made was **SW7 OFF → ON**; SW8/9/10 verified still OFF.
Both ₱50 and ₱100 are accepted now. Two readings fit that equally well:

| | SW6 | SW7 | SW8 | SW9 | SW10 |
| --- | --- | --- | --- | --- | --- |
| **A** (from MXP6 sheet shape) | ₱20 | **₱50 & ₱100** | ₱200 | ₱500 | ₱1000 |
| **B** (operator-reported) | **₱20 & ₱50** | ₱100 | ₱200 | ₱500 | ₱1000 |

Both predict today's observed behaviour with SW6+SW7 ON. They differ on one
point only: **with SW7 OFF, is ₱50 accepted?** A says no, B says yes.

Weak evidence for B: the original V1 brief reported a ₱50 being accepted under
the factory config (SW6 ON, SW7 OFF). That observation predates the wiring fix
and could not distinguish stacking from rejection, so it is not decisive.

**Discriminating test (~1 minute):** set SW7 OFF, power-cycle, insert ₱50.
Accepted → B. Returned → A. Restore SW7 ON afterwards.

Either way the current configuration is correct and safe: ₱20/₱50/₱100
enabled, ₱200/₱500/₱1000 refused. The ambiguity affects documentation only,
not behaviour.

This falsifies the per-denomination reading taken from the Mexican MXP6 sheet.
On this PH6 build, **SW7 = ₱50 & ₱100 as one group**. Grouping is normal in
this device family — the MXP6 sheet groups ₱500 & ₱1000 on SW10, and the ICT
TAO-A.V PHP6 sheet groups ₱100 & ₱200 — the PH build simply groups a different
pair. Six denominations across five switches requires exactly one such pair.

Bank state as measured:

| SW | Function | State | Effect | Basis |
| --- | --- | --- | --- | --- |
| 1,2,3 | scaling | OFF/OFF/OFF | 1 pulse / ₱10 | ✅ measured |
| 4 | speed | ON | Fast 50/100 | ✅ measured |
| 5 | inhibit level | OFF | Active High | vendor sheet |
| 6 | ₱20 | ON | accepted | inferred, **untested** |
| 7 | **₱50 & ₱100** | **ON** | both accepted | ✅ measured |
| 8 | ₱200 | OFF | rejected | inferred, untested |
| 9 | ₱500 | OFF | rejected | inferred, untested |
| 10 | ₱1000 | OFF | rejected | inferred, untested |

**This is already the target configuration.** ₱20/₱50/₱100 are enabled and
₱200/₱500/₱1000 are refused at the acceptor, which is the correct policy for a
kiosk that gives no change. No further DIP changes are required; SW8/9/10 must
stay OFF.

Untested gaps: ₱20 acceptance (SW6), and rejection of ₱200/₱500/₱1000. All
three switches being OFF is the fail-safe direction, so the residual risk is
low, but the rejection trials still belong in the Phase-0 worksheet.

## 2. The DIP switch map (this is the answer to "are my dips correct")

Source: genuine TOPVME **TB74** sheet for MXP6 (`20/50/100/200/500/1000`),
the same six-bill structure as PHP6, on the same 10-way + 4-way banks.
See `hardware/references/vendor-dip-sheets/`.

### DIP SW SETTING 1 — the 10-way bank (CTS195-10)

| SW | Function | Your setting | Verdict |
| --- | --- | --- | --- |
| 1,2,3 | Pulse scaling (see table below) | OFF/OFF/OFF = **1 pulse / ₱10** | correct (default) |
| 4 | ON = Fast 50/100 ms · OFF = Slow 50/300 ms | **ON** = Fast | good — keep |
| 5 | ON = Inhibit Active Low · OFF = Active High | OFF = Active High | correct (default) |
| 6 | ON = Accept ₱20 | **ON** | correct |
| 7 | ON = Accept **₱50 & ₱100** | **ON** (after fix) | correct — see §1b |
| 8 | ON = Accept ₱200 | OFF | correct for this project |
| 9 | ON = Accept ₱500 | OFF | correct for this project |
| 10 | ON = Accept ₱1000 | OFF | correct for this project |

The SW6–SW10 denomination assignment above is the **measured PH6 mapping**, not
the Mexican MXP6 sheet's. The MXP6 sheet assigns one note per switch for
SW6–SW9 and groups ₱500 & ₱1000 on SW10; the PH6 build instead groups
₱50 & ₱100 on SW7. Bench evidence in §1b overrides the sheet here.

Pulse scaling options (SW1/SW2/SW3):

| SW1 | SW2 | SW3 | Scaling |
| --- | --- | --- | --- |
| OFF | OFF | OFF | **1 pulse / ₱10** ← default, and what you have |
| OFF | OFF | ON | 2 pulses / ₱10 |
| OFF | ON | OFF | 3 pulses / ₱10 |
| OFF | ON | ON | 4 pulses / ₱10 |
| ON | OFF | OFF | 5 pulses / ₱10 |
| ON | OFF | ON | 10 pulses / ₱10 |
| ON | ON | OFF | 20 pulses / ₱10 |
| ON | ON | ON | 100 pulses / ₱10 |

### DIP SW SETTING 2 — the 4-way bank (CTS208-4)

| SW | Function | Your setting | Verdict |
| --- | --- | --- | --- |
| 1 | ON = Pulse Normal **High** (NO) · OFF = Normal Low (NC) | **ON** | correct — matches your observed idle-HIGH |
| 2 | ON = **Pulse Protocol** · OFF = RS232 Protocol | **ON** | correct — **this is the protocol answer** |
| 3 | Reserved | OFF | correct (default) |
| 4 | Reserved | OFF | correct (default) |

**The whole 4-way bank is already exactly right.** You are in Pulse mode,
normally-high, and that is why counting FALLING edges is the correct approach.

### The change required

Move **SW7 → ON** on the 10-way bank. Nothing else — that single switch
enables both ₱50 and ₱100. **Done and verified**; see §1b.

Then **power-cycle the acceptor** — the vendor sheet states "Please reset the
bill acceptor after any changes on Dip switch." A DIP change without a reset
does not take effect, which is a plausible reason earlier switch experiments
appeared to do nothing.

Leaving SW9 and SW10 OFF is deliberate and correct: it makes the acceptor
physically refuse ₱200/₱500/₱1000, which is the right policy for a kiosk that
gives no change and already caps carts at 3 units/item and 5 distinct items.

### Cross-check available right now, before any wiring change

The TB manual's troubleshooting table (printed page 17) states:

> Red LED, 2 flashes → **Disable** → "Check if the DIP switch setting is correct"

Insert a ₱50 and watch the LED and the note. If the note is drawn in, paused,
and **returned**, it was rejected — which is what the DIP map predicts. If it
is **stacked and kept**, then the note was genuinely accepted and the bank
mapping needs re-derivation from the bench instead.

---

## 3. PHP denomination decoding

PH6 = the six circulating Philippine notes: **₱20, ₱50, ₱100, ₱200, ₱500,
₱1000**. Confirmed by two independent PHP6 currency sheets.

The pulse base unit is **₱10** — the GCD of the six denominations. This is why
₱10 appears in the scaling table even though no ₱10 note exists.

At your current `1 pulse / ₱10` scaling and SW4=Fast (150 ms period):

| Note | Expected pulses | Expected train duration | Enabled by |
| --- | ---: | ---: | --- |
| ₱20 | **2** | ~0.30 s | SW6 (ON now) |
| ₱50 | **5** | ~0.75 s | SW7 (needs ON) |
| ₱100 | **10** | ~1.50 s | SW8 (needs ON) |
| ₱200 | 20 | ~3.0 s | SW9 — intentionally OFF |
| ₱500 | 50 | ~7.5 s | SW10 — intentionally OFF |
| ₱1000 | 100 | ~15 s | SW10 — intentionally OFF |

Note how badly Slow mode scales: on SW4=OFF the period is 350 ms, so ₱100
would take 3.5 s and ₱1000 would take 35 s. **Keep SW4 = ON.**

This vindicates the V1 sketch's `billValuePerPulse = 10`. That constant was
right; the DIP configuration and the signal conditioning were not.

---

## 4. Repository trace — answers to the brief's ten questions

An exhaustive keyword sweep (`attachInterrupt`, `pulseIn`, `Serial.begin`,
`SoftwareSerial`, `ccTalk`, `ID003`, `TB74`, `TOPVME`, denomination literals,
checksum/frame markers) across every tree including the archived `_For-Mendo/`
v1/v2 system returned matches in only these files:

```
Bill_Acceptor.ino                                (41 lines, root)
hardware/references/legacy/Bill_Acceptor.ino     (same file, archived)
hardware/firmware/bill_observer/bill_observer.ino
hardware/firmware/mendo_controller/mendo_controller.ino
hardware/firmware/bench_safe/bench_safe.ino
hardware/{README,tb-arduino-uno-wiring}.md, .svg
CHECKPOINT.md
```

**`_For-Mendo/` contains no bill-validator code at all.** There is no hidden
protocol parser, no packet decoder, no lookup table, and no second serial port
anywhere in this repository.

| # | Question | Answer |
| --- | --- | --- |
| 1 | Pulse, RS232, ccTalk or ID003? | **Pulse.** DIP2 SW2=ON. No serial parser exists in any tree. |
| 2 | Where is bill acceptance handled? | `Bill_Acceptor.ino` only — a 41-line ISR counter. Nothing else predates this project. |
| 3 | How is denomination determined? | It is not. The V1 sketch multiplies a raw count by ₱10 and accumulates a single `credit` integer. No per-note identification. |
| 4 | Packet decoding? | **None.** No checksum, frame, header, or byte-marker logic exists. |
| 5 | Pulse counting? | Yes — `attachInterrupt(digitalPinToInterrupt(2), billPulseISR, FALLING)` with a 50 ms ISR debounce and a 250 ms train-settle in `loop()`. |
| 6 | PHP denomination lookup table? | Not in V1. The current repo has one: `hardware/config.example.toml` → `{2:2000, 5:5000, 10:10000}` centavos, mirrored in `hardware/simulator.py:30`. **This analysis confirms those three values are correct.** |
| 7 | Undocumented TB74 constants? | Only `billValuePerPulse = 10`. Now explained: it is the ₱10 pulse base unit. |
| 8 | Which Arduino pins? | V1 used **D2/INT0**. The current locked mapping uses **D3/INT1** for the TB meter and reserves D2/INT0 for the Allan coin acceptor (`hardware/README.md`). |
| 9 | Baud rate? | `9600` in V1 — that is the **USB debug console only**, not a validator link. Current firmware uses `115200`, also host-side only. There is no serial connection to the acceptor. |
| 10 | Hidden protocol parser? | No. |

### Execution path (V1, as-built)

```
Bill inserted
  → TB74 validates, and IF the denomination is enabled, stacks the note
  → opto-isolated Credit O/P pulls METER+ LOW, N times, 50 ms LOW / 100 ms HIGH
  → D2 FALLING interrupt → billPulseISR() → pulseCount++ (50 ms debounce)
  → loop(): 250 ms of quiet → credit += pulseCount * 10 → Serial.print
  → (no vending logic — the sketch ends here)
```

There is no session binding, no idempotency, no inhibit control, and no
acknowledgement. Everything downstream of "credit" was never implemented in
V1; the durable order/dispense state machine in `pos/order_service.py` and
`hardware/` is new work in this project.

### Hardware pins and ports

| Signal | TB pin | Harness colour | Arduino | Notes |
| --- | --- | --- | --- | --- |
| +12 V | 5 | Red | — | separate fused supply, never an Uno pin |
| 12 V GND | 9 | Orange | — | supply return only |
| METER+ | 7 | Blue | **D3 / INT1** | needs external 4.7 kΩ pull-up to Uno 5 V |
| METER- | 8 | Purple | Uno logic GND | |
| INHIBIT+ | 1 | Yellow | via 1 kΩ to 5 V | Active **High** (SW5=OFF) |
| INHIBIT- | 2 | Green | NPN collector from D4 | |

Serial ports in use: **one** — the Uno USB CDC to the host, 115200 baud. The
acceptor is not on any UART.

---

## 5. Firmware constants that are wrong for this device

Not applied — the brief asked for understanding before rewriting. Recorded
here so the changes are deliberate.

| Location | Constant | Problem | Suggested |
| --- | --- | --- | --- |
| `mendo_controller.ino:42` | `BILL_GAP_MS = 180` | Below the 350 ms Slow-mode period. If SW4 is ever OFF, every single pulse is emitted as its own event — a ₱100 note becomes ten ₱10 credits. Only 30 ms of margin even in Fast mode. | **500** |
| `mendo_controller.ino:279` | `billEdge()` bounce filter `< 3` ms | Passes the entire 8–20 ms motor-noise band straight into the counter. Real minimum period is 150 ms. | **25** ms |
| `bill_observer.ino` | `TRAIN_GAP_US = 250000` | Same Slow-mode splitting problem. | **500000** |
| `hardware/pulses.py` | `PulseMapping(bills=...)` defaults to `{}` | Bill mapping is empty by default while coins are pre-populated; a real bill train would map to `None`. | seed `{2:2000, 5:5000, 10:10000}` |
| `bill_observer.ino` | `candidateCentavos()` marked `UNVERIFIED_V1_HYPOTHESIS` | The 2/5/10 → ₱20/₱50/₱100 mapping is now **documented from the vendor sheet**. Still needs bench trials, but it is no longer a guess. | reword to "vendor-documented, bench-pending" |

Electrical, before any re-test: fit the **4.7 kΩ pull-up from D3 to Uno 5 V**
and drop `INPUT_PULLUP` in favour of plain `INPUT`. `bill_observer.ino`
already assumes this; the root `Bill_Acceptor.ino` does not.

---

## 6. Recommended bench sequence

1. Set 10-way SW7 → ON, SW8 → ON. Leave everything else. **Power-cycle.**
2. Fit the external 4.7 kΩ pull-up on the METER node.
3. Flash `bill_observer.ino` (observe-only; drives no inhibit, no servo).
4. Send `ARM`, insert ₱20, ₱50, ₱100 one at a time.
5. Expect **2 / 5 / 10** falling edges, `PULSE_WIDTH_AVG_US ≈ 50000`,
   `INTERPULSE_GAP_AVG_US ≈ 150000`. Any gap under 80 ms is still noise —
   stop and fix conditioning before going further.
6. Confirm ₱200/₱500/₱1000 are returned, not stacked.
7. Twenty consecutive correct trials per enabled denomination, then fill in the
   `hardware/README.md` Phase-0 worksheet rows.

Until step 7 is complete and the R1–R4 remediation checkpoints are approved,
`MENDO_HARDWARE_MODE` stays `simulator`.

---

## 7. Confidence

| Claim | Confidence | Basis |
| --- | --- | --- |
| Protocol is Pulse, not RS232 | **Confirmed** | Measured credit train on METER; DIP2 SW2=ON; no serial parser in any tree |
| 1 pulse = ₱10 | **Confirmed** | ₱50 note produced exactly 5 pulses |
| Fast timing, 50 ms LOW / 150 ms period | **Confirmed** | Measured 50/50/50 and 150/150/151 |
| METER+ belongs on D3 with a 4.7 kΩ pull-up | **Confirmed** | Clean train only after the rewire |
| Sub-80 ms events are noise, not credit | **Confirmed** | 2317 raw edges vs 5 real pulses in one window |
| PHP6 = ₱20/50/100/200/500/1000 | **High** | Two independent PHP6 currency sheets |
| 10-way SW1-3 scaling, SW4 speed, SW5 inhibit | **High** | TB74 vendor sheet; SW1-3 and SW4 both verified by the measured result |
| SW6–SW10 are denominations, ON = accept | **Confirmed** | SW7 alone moved OFF→ON and denominations changed state |
| ₱20/₱50/₱100 = 2/5/10 pulses | **Confirmed** | All three trialled 23:23, session total exact at ₱170 |
| No false credit on a rejected note | **Confirmed** | 6 rejections, 23,064 raw edges, ₱0 credited |
| Which switch holds ₱50 (SW6 vs SW7) | **Unresolved** | Candidates A and B in §1b both fit; needs the SW7-OFF ₱50 test |
| SW8/9/10 = ₱200/₱500/₱1000 | **Medium** | Inferred; untested. All OFF is the fail-safe direction |

The protocol itself is fully measured. The per-switch assignment for SW6 and
SW8–SW10 remains inferred, but every one of those switches is OFF except SW6,
so the configuration is already the intended one and errors there cannot
enable an unwanted denomination.

Remaining Phase-0 coverage: ₱20 acceptance, twenty consecutive correct trials
per enabled denomination, and rejection trials for ₱200/₱500/₱1000 as notes
become available.

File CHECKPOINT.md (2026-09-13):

# MendoVendo hardware/payment integration checkpoint

This file is append-only for phase records and decisions. It is the hand-off
document for resuming the integration without assuming that unmeasured
hardware behavior is safe.

## Resume here

- Current phase: **R0 audit record complete; R1 firmware remediation awaiting
  user approval**
- Current status: **software Phases 1–2 remediation required; real hardware
  remains disabled**
- Safe next action: review the R0 findings below and explicitly approve R1
  before any firmware behavior is changed. Physical work remains blocked until
  the worksheet below (TB identity/PHP sheet, continuity, DIP polarity, pulse
  captures, 0–5 V signals, and servo measurements) is completed.
- Cash and dispensing state: simulator events are enabled for tests only;
  real cash and real motion remain disabled and no Flask worker opens a serial
  device.
- User approval to continue software implementation: **previously approved in
  the 2026-08-03 user request because hardware is currently unavailable**;
  approval to begin R1 after this audit: **pending**.
- Physical Phase 0 completion approval: pending evidence and user review.

## Phase 0 — Baseline and hardware identity

- Status: blocked
- Manila date/time: 2026-08-03 13:05:10 PST (+0800)
- Branch: `experiment-march-1`
- Base commit: `41b2bbd` (working tree changes are not committed)

### Goal and acceptance criteria

Establish a reproducible software baseline and an auditable identity/evidence
record for the Allan coin acceptor, TOPVME TB bill acceptor, and rotor asset.
Phase 0 can complete only when the physical TB identity, PHP configuration,
harness continuity, DIP polarity, supported-denomination pulse counts, and
conditioned Arduino-side voltages are measured and recorded.

### Files/schema changed

- `CHECKPOINT.md` — created as the first implementation change.
- `hardware/README.md` — safety, wiring, calibration, and Phase-0 evidence
  worksheet.
- `hardware/references/README.md` — provenance and hashes for tracked copies.
- `hardware/references/` — tracked-copy location for the two manuals and STL.
- `pytest.ini` — scopes pytest to `testing/`, excluding archived binary
  artifacts from collection.
- `README.md` and `CLAUDE.md` — synchronized Phase-0 status and hand-off
  guidance.
- No database schema or runtime payment behavior has been changed.
- The supplied root-level reference files remain untouched; their tracked
  copies are under `hardware/references/`.

### Exact baseline commands and results

- `./.venv/bin/python -m unittest discover -s testing -p 'test_*.py' -q`
  — **92 tests, OK** (2026-08-03).
- `./.venv/bin/python -m pytest -q` — **92 passed, 52 subtests passed** in
  27.27 seconds after adding `pytest.ini` to scope discovery to `testing/`.
  Before that config, pytest discovered the archived binary-named file
  `_For-Mendo/testing/test_output.txt` and failed during collection; that was
  a test-discovery issue, not an application test failure.

### Hardware measurements, photos, pulse captures, and calibration values

- Allan reference: `allan coinslot calibration.pdf`, four pages, dated
  2020-08-27. It describes six coin programs (old/new ₱1, ₱5, and ₱10),
  calibration samples, and standard sensitivity `F=8`; the supplied plan
  selects `H=20`, `P=1/5/10`.
- TB reference: `tb_series.pdf`, 24 pages. It documents generic TB74/TB77
  dimensions, 12 V ±10% supply, pulse/RS232/ccTalk/ID003 interfaces, and the
  WEL-R7U02 harness. It does **not** identify the connected unit’s exact model,
  PHP firmware label, currency DIP sheet, or observed pulse mapping.
- WEL-R7U02 colors documented by the manual: red `+12 V`, orange `GND`, blue
  `METER+`, purple `METER-`, yellow `INHIBIT+`, green `INHIBIT-`.
  Continuity has not yet been measured on the physical harness.
- No physical photos, pulse-width captures, pulse-gap captures, denomination
  trials, DIP-bank readings, or conditioned 0–5 V measurements are available
  in this workspace.
- Rotor source: `rotor_9pocket_35x20_recommended_clearance.stl` is preserved;
  the plan describes it as a watertight 172 × 172 × 16 mm rotor. No hardware
  cycle or loaded-dispense measurement has been performed.

### Decisions or deviations

- The application remains cash-disabled until physical evidence passes the
  Phase-0 gate.
- Reference documents are treated as wiring/calibration guidance, not proof of
  the installed acceptor’s identity or behavior.
- No TB Philippine DIP settings are inferred from a TP-series document.
- The existing 92-test suite is the baseline; the new hardware/payment suite
  must be additive.
- Test discovery is scoped to the live `testing/` suite so future hardware
  tests can run with the same command without reading archived artifacts.

### Known risks and rollback/recovery

- Wrong TB model, DIP polarity, or pulse mapping could credit the wrong amount
  or fail to inhibit on reset. Keep the acceptors physically disconnected or
  inhibited until measured.
- The Allan COIN signal voltage is unknown; never connect it directly to Uno
  D2. Use the specified 12 V-rated optocoupler interface and verify its output
  is 0–5 V first.
- If a later phase is unsafe, disable the daemon/acceptor power controls and
  retain the SQLite event/job evidence for manual review. No financial refund
  may restore physical stock without an explicit return-to-stock action.

### Documentation updated

- The checkpoint, hardware guide, README, and `CLAUDE.md` are synchronized for
  the current evidence state. Physical measurements are still required before
  this phase can be marked complete.

### User approval

- Phase 0 completion approval: pending physical evidence and user review.
- Approval to begin Phase 1: pending.
- Clarification recorded 2026-08-03: the user approved simulator/software
  continuation while physical Phase 0 remains incomplete; this does not
  approve real hardware enablement.

## Append-only decision log

### D-0001 — 2026-08-03, Phase 0

Use the repository’s supported unittest discovery command as the baseline:
92/92 tests pass. Raw pytest discovery is not an acceptance command until it
is scoped away from the archived `_For-Mendo` artifacts.

### D-0002 — 2026-08-03, Phase 0

The supplied TB installation guide is insufficient to authorize PHP cash
acceptance. Exact model/firmware, currency DIP sheet, polarity, pulse mapping,
and voltage measurements remain physical acceptance evidence requirements.

### D-0003 — 2026-08-03, Phase 0

The root-level supplied manuals and STL are preserved as originals. Tracked
copies may be placed under `hardware/references/` with provenance and hashes;
the originals must not be deleted or overwritten.

### D-0004 — 2026-08-03, Phase 0

Scope pytest discovery to `testing/` with `pytest.ini`. The live suite now
passes under both the supported unittest command and `./.venv/bin/python -m
pytest -q` (92 tests; 52 subtests reported by pytest).

## Phase 1 — order and inventory foundation (software-only)

- Status: **complete for simulator/software scope; physical acceptance pending**
- Manila date/time: 2026-08-03 14:08:37 PST (+0800)
- Branch: `experiment-march-1`
- Commit: `41b2bbd` base; implementation is currently an uncommitted working
  tree and must be reviewed before commit.

### Goal and acceptance criteria

Add a recoverable additive order layer without deleting historical
transactions: integer-centavo totals, ten-slot catalog snapshots,
`stock_quantity - reserved_quantity` availability, exactly-once cash events,
sequential per-unit dispense jobs, idempotent final receipts, cashbox
reconciliation, legal transitions, timeout handling, and explicit recovery
actions.

### Files/schema changed

- `mendo_core/money.py` — Decimal-to-centavo conversion and PHP formatting.
- `pos/db.py` — additive orders, order items, cash sessions/events, payment
  attempts, motion profiles, dispense jobs, cashbox sessions, audit events,
  reserved inventory, cashbox assignment, and restock audit fields.
- `pos/order_service.py` — transactional lifecycle and recovery service.
- `pos/routes_checkout.py`, `pos/routes_shop.py`, `pos/routes_admin.py` — kiosk,
  cashier, Xendit, hardware, audit, cashbox, and staff-recovery APIs.
- `web/static/js/pos.js`, `web/static/js/kiosk-checkout.js`, checkout/shop/admin
  templates — centavo-aware status and payment/dispensing UI.

### Exact test/build commands and results

- `./.venv/bin/python -m unittest discover -s testing -p 'test_*.py' -q` —
  baseline recorded before implementation: **92 tests, OK**.
- `./.venv/bin/python -m pytest -q testing/test_hardware_payment.py` —
  **19 passed**.
- `./.venv/bin/python -m pytest -q` — **111 passed, 52 subtests passed** in
  33.35 seconds.
- `./.venv/bin/python -m compileall -q mendo_core pos hardware testing` —
  **exit 0**.

### Hardware measurements and calibration values

None are available. The ₱20/₱50/₱100 bill pulse fixture `{2: 2000, 5: 5000,
10: 10000}` and the ten `1500/1900 µs` motion profiles are explicitly marked
simulator/unmeasured and are not evidence about the installed hardware.

### Decisions or deviations

- The user authorized continuing with software and simulator work because the
  hardware cannot currently be used.
- Real refunds do not restore physical stock. Reservations for undispensed
  units are released; physical stock rises only through an explicit staff
  return-to-stock action.
- The legacy transaction table remains a receipt projection for compatibility;
  the new order tables are the financial source of truth.

### Known risks and rollback/recovery instructions

- Do not infer TB PHP DIP settings or pulse mappings from the reference PDF.
- If a software regression appears, run the baseline unittest command and
  preserve the SQLite order/cash/job rows for review; do not delete or reset
  the database as a recovery shortcut.
- Set `MENDO_HARDWARE_MODE=simulator` for development. Never clear the real
  firmware/configuration evidence gate to bypass missing measurements.

### Documentation updated

`README.md`, `CLAUDE.md`, `hardware/README.md`,
`docs/architecture/cash-order-integration.md`, and this checkpoint were
synchronized. User-facing fulfillment wording is `dispensed_unverified` /
“actuator acknowledged” until a shared chute sensor exists.

### Next safe action

Continue Phase 2 software validation; no physical connection is required.
When hardware becomes available, resume Phase 0 evidence capture before any
real cash session.

### User approval

- Simulator/software continuation: **approved by the user on 2026-08-03**.
- Physical Phase 0 completion: pending.

## Phase 2 — hardware interface and simulator (software-only)

- Status: **complete for socket/simulator/real-daemon source; bench acceptance
  deferred**
- Manila date/time: 2026-08-03 14:08:37 PST (+0800)
- Branch: `experiment-march-1`
- Commit: `41b2bbd` base; implementation is uncommitted and must be reviewed
  before commit.

### Goal and acceptance criteria

Provide one bounded protocol and one serial owner, with explicit simulator and
real modes, fail-safe health, CRC16 frames, a Unix-domain Flask boundary,
firmware identity/protocol/configuration checks, heartbeat behavior, job
idempotency, and fault-injection coverage without opening a real serial device
in tests.

### Files changed

- `hardware/protocol.py`, `pulses.py`, `interface.py`, `simulator.py` — bounded
  ASCII frames, CRC, pulse grouping, contracts, and deterministic faults.
- `hardware/daemon.py`, `real_backend.py`, `daemon_main.py`, `serial_bridge.py`,
  `service.py` — Unix socket daemon, pyserial-owned real backend, client, and
  Flask service boundary.
- `hardware/firmware/mendo_controller/mendo_controller.ino` and
  `hardware/firmware/platformio.ini` — shared Uno/Mega source, fail-safe pins,
  interrupts, pulse finalization, CRC validation, EEPROM evidence/job rings,
  A→B→A job identity protection, heartbeat, and PCA OE control.
- `hardware/udev/99-mendo-uno.rules`, `hardware/systemd/mendo-hardware.service`,
  and `hardware/config.example.toml` — restricted daemon deployment examples.
- `testing/test_hardware_payment.py` — 19 simulator/payment/daemon tests.

### Exact test/build commands and results

- `./.venv/bin/python -m pytest -q testing/test_hardware_payment.py` —
  **19 passed**.
- `./.venv/bin/python -m pytest -q` — **111 passed, 52 subtests passed**.
- `./.venv/bin/python -m compileall -q mendo_core pos hardware testing` —
  **exit 0**.
- PlatformIO/Arduino hardware compilation and PTY Arduino integration were
  **not run**: the board is unavailable and PlatformIO is not installed in
  this environment. The Unix-socket simulator round trip did pass.

### Hardware measurements and calibration values

No physical measurements, photos, pulse captures, loaded servo trials, or
flash/SRAM reports are available. The firmware constant
`PHYSICAL_EVIDENCE_CONFIRMED` remains false. Real mode therefore refuses cash
until measured configuration is reported by the controller and the service
health gate passes.

### Decisions or deviations

- Simulator mode is intentionally visible in every order/status response and
  says that events are synthetic.
- The planned PTY-based Arduino test is deferred; the current automated
  boundary test uses a Unix socket with the same framed protocol.
- No production override was added for missing hardware evidence.

### Known risks and rollback/recovery instructions

- Do not run `MENDO_HARDWARE_MODE=real` without the udev identity, dedicated
  daemon account, exact harness verification, and measured fail-safe polarity.
- To roll back hardware behavior, stop `mendo-hardware.service`, use simulator
  mode, and leave acceptors/PCA OE physically disabled.
- A lost dispense ACK must be resolved with `JOB_STATUS`/staff review; never
  issue a second physical command solely because an ACK was lost.

### Documentation updated

`hardware/README.md`, firmware README/configuration, systemd/udev examples,
`README.md`, `CLAUDE.md`, `docs/architecture/cash-order-integration.md`, and
this checkpoint were synchronized.

### Next safe action

Keep automated development in simulator mode. When hardware becomes available,
finish Phase 0, then compile the identical firmware for Uno and Mega, capture
flash/SRAM usage, and run pulse-generator tests before powering either
acceptor.

### User approval

- Simulator/software continuation: **approved by the user on 2026-08-03**.
- Real hardware enablement: pending Phase-0 evidence and explicit review.

## Resume here — physical work only

1. Identify the exact TB model, PHP firmware label, harness continuity, DIP
   banks, and inhibit polarity.
2. Capture Allan coin and TB bill pulse width/gap/count evidence with the
   conditioned Arduino-side signals verified at 0–5 V.
3. Record the evidence files/photos under `hardware/evidence/` and update the
   Phase-0 worksheet and decision log.
4. Only after review, replace simulator/unmeasured mappings, compile Uno and
   Mega, and begin one-device-at-a-time bench tests.

## Append-only decision log (continued)

### D-0005 — 2026-08-03, software continuation

The user explicitly authorized implementation to continue while the physical
hardware is unavailable. Software and simulator phases may proceed, but this
does not approve real cash, real dispensing, inferred TB settings, or a
physical Phase-0 completion.

### D-0006 — 2026-08-03, hardware safety gate

The shared firmware source keeps `PHYSICAL_EVIDENCE_CONFIRMED=false`, starts
with acceptors inhibited and PCA OE disabled, and reports the missing
configuration/evidence gate. Development uses only the visibly labelled
simulator until the worksheet is reviewed.

### D-0007 — 2026-08-03, recovery semantics

An unknown controller result is never retried automatically. Staff may retry
only a job explicitly marked `unexecuted`; a financial refund never restores
physical stock, and return-to-stock is a separate staff-confirmed action.

## Software consistency addendum — 2026-08-03

- Status: **complete for simulator/software scope; physical acceptance remains blocked**
- Manila date/time: 2026-08-03 14:41:17 PST (+0800)
- Branch: `experiment-march-1`
- Commit: `41b2bbd` base; working tree remains uncommitted.

### Goal and acceptance criteria

Keep the compatibility lifecycle field `orders.fulfillment_state` while adding
an explicit actuator-result field. Completed servo acknowledgments must be
reported as `dispensed_unverified`; cancellations, manual review, refund,
retry, and migration paths must not lose that distinction. Existing databases
must migrate additively.

### Files/schema changed

- `pos/db.py` — additive `orders.fulfillment_result` field and migration.
- `pos/order_service.py` — fulfillment-result projection and state updates.
- `testing/test_hardware_payment.py` — migrated-database and unverified-result
  assertions.

### Exact test/build commands and results

- `./.venv/bin/python -m pytest testing/test_hardware_payment.py -q` —
  **20 passed**.
- `./.venv/bin/python -m pytest -q` — **rerun required after this addendum**;
  the preceding full run was **111 passed, 52 subtests passed**.
- Physical firmware compilation, PTY Arduino integration, and hardware trials
  remain deferred because the hardware is unavailable.

### Hardware measurements, photos, pulse captures, and calibration values

None. This addendum changes no physical mapping. Simulator bill mappings and
unmeasured servo profiles remain synthetic and gated.

### Decisions or deviations

`fulfillment_state=completed` remains for historical/API compatibility, while
`fulfillment_result=dispensed_unverified` is the authoritative prototype
verification label. A future chute sensor may introduce a verified result
without rewriting historical orders.

### Known risks and rollback/recovery instructions

Do not interpret a completed actuator job as proof of a physical drop. If the
migration or state projection regresses, preserve the order/job/cash evidence,
run the full test command, and keep real mode disabled; do not delete or reset
the production SQLite database.

### Documentation updated

This checkpoint and the existing architecture/hardware hand-off documents
remain synchronized with the deferred physical gate.

### Next safe action

Run the final full software checks. When hardware becomes available, resume
the physical Phase-0 worksheet before clearing `PHYSICAL_EVIDENCE_CONFIRMED`.

### User approval

- Software continuation: **approved by the user on 2026-08-03**.
- Physical enablement: pending measurements and explicit review.

### D-0008 — 2026-08-03, actuator-result vocabulary

Use `dispensed_unverified` for the initial fulfillment result. The legacy
`completed` lifecycle state is retained only as a compatibility projection;
the system must never claim a chute drop until a shared chute sensor is
installed and validated.

## Final software verification — 2026-08-03

- Status: **complete for the authorized simulator/software scope**
- Manila date/time: 2026-08-03 (final verification after the consistency addendum)
- Branch: `experiment-march-1`
- Commit: `41b2bbd` base; no commit was created by this implementation pass.
- Exact results:
  - `./.venv/bin/python -m pytest -q` — **112 passed, 52 subtests passed**.
  - `./.venv/bin/python -m compileall -q mendo_core pos hardware testing` — **exit 0**.
  - `node --check web/static/js/kiosk-checkout.js && node --check web/static/js/pos.js` — **exit 0**.
  - `git diff --check` — **clean**.
- Hardware measurements/photos/pulse captures/calibration: **not available**;
  physical Phase 0 remains blocked and no real-device acceptance claim is made.
- Next safe action: preserve simulator mode, then resume the physical worksheet
  and review this checkpoint when the hardware is available.
- User approval: software continuation approved; real hardware enablement
  remains pending evidence and explicit review.

## Final software verification continuation — 2026-08-03

- Status: **complete for the authorized simulator/software scope**
- Files changed since the preceding verification: `pos/order_service.py`,
  `pos/routes_checkout.py`, `pos/routes_admin.py`, `hardware/real_backend.py`,
  `testing/test_hardware_payment.py`, and synchronized architecture/hardware/
  assistant documentation.
- Exact results:
  - `./.venv/bin/python -m pytest -q` — **113 passed, 52 subtests passed**.
  - `./.venv/bin/python -m compileall -q mendo_core pos hardware testing` — **exit 0**.
  - `node --check web/static/js/kiosk-checkout.js && node --check web/static/js/pos.js` — **exit 0**.
  - `git diff --check` — **clean**.
- Recovery acceptance: a lost dispense response is reconciled by immutable
  job ID; the simulator test confirms one physical-motion record and one stock
  deduction. No hardware acceptance evidence exists.
- Known risk/rollback: real firmware compilation and bench tests remain
  unavailable; keep `MENDO_HARDWARE_MODE=simulator` and the physical evidence
  gate closed. Stop the daemon and preserve SQLite evidence if a future bench
  test fails.
- Next safe action: physical Phase 0 worksheet, then Uno/Mega compilation and
  pulse-generator tests when the user has the hardware.
- User approval: software continuation approved; physical enablement pending.

### End-to-end simulator smoke verification

Using a temporary SQLite database with seeded stock and
`MENDO_HARDWARE_MODE=simulator`, the public flow returned:

- `POST /checkout/api/orders` → **201**, due `₱9.50`.
- `POST /checkout/api/orders/<ref>/cash/start` with consent → **200**,
  `awaiting_cash`.
- `POST /checkout/api/orders/<ref>/cash/simulate` with ₱10 → **200**, `paid`,
  `dispensed_unverified`, overpayment `₱0.50`.
- Polling `GET /checkout/api/orders/<ref>` → **200**,
  `dispensed_unverified`.
- Unknown order → **404**; no fingerprint route registered.

## TB-to-Arduino Uno wiring diagram addendum — 2026-08-03 17:04 PST

- Status: **complete for the documentation artifact; physical Phase 0 remains blocked**.
- Manila date/time: 2026-08-03 17:04 PST (+0800)
- Branch: `experiment-march-1`
- Commit: no commit created by this addendum.
- Goal and acceptance criteria: provide an editable, print-ready bench diagram
  for the TB WEL-R7U02 harness, isolated METER input, NPN inhibit interface,
  Arduino D3/D4/GND connections, and separate 12 V/5 V domains. The diagram
  explicitly gates power-up on continuity, exact PHP DIP/polarity, and 0–5 V
  measurements.
- Files changed: `hardware/tb-arduino-uno-wiring.svg`,
  `hardware/tb-arduino-uno-wiring.md`, and `hardware/README.md`.
- Exact validation commands and results:
  - `google-chrome --headless --no-sandbox --disable-gpu --hide-scrollbars --window-size=1600,1400 --screenshot=/tmp/mendo-tb-uno-wiring-final.png file:///home/yyerf/school/mendo-testing/hardware/tb-arduino-uno-wiring.svg` — rendered and visually inspected.
  - `./.venv/bin/python -m pytest -q` — prior synchronized software result:
    **113 passed, 52 subtests passed**; this documentation-only addendum does
    not change runtime code.
  - `git diff --check` — **clean**.
- Hardware measurements, photos, pulse captures, and calibration values:
  **none**. The diagram is based on the supplied manual only; it is not a
  substitute for identifying the connected unit or measuring its signals.
- Decisions/deviations: exact TB model, PHP firmware/DIP sheet, inhibit
  polarity, R3/R4 values, and pulse mapping remain bench evidence gates.
  Higher bills remain disabled by the application configuration.
- Known risks and rollback/recovery: do not connect the TB 12 V rail to the
  Uno. If the physical bench test disagrees with the diagram, keep real mode
  disabled, record the measured harness/polarity, and correct the diagram and
  checkpoint before powering the interface.
- Documentation updated: `hardware/README.md`, the editable SVG diagram, and
  the companion connection guide.
- Next safe action: when hardware is available, complete the Phase-0 worksheet
  and verify the exact TB harness, PHP DIP sheet, fail-safe inhibit state, and
  conditioned 0–5 V signals before any application checkout.
- User approval: diagram delivered; physical enablement still requires the
  user's measurements and explicit review.

## Phase R0 — Correct the audit record — 2026-08-03 18:27:15 PST (+0800)

- Status: **complete for the audit/documentation record; remediation required**.
- Branch: `experiment-march-1`.
- Base commit: `41b2bbd`; working tree is intentionally uncommitted and dirty
  from the prior software implementation plus this R0 record.
- Goal and acceptance criteria: classify the supplied V1 bill sketch as
  unverified legacy evidence, record every release-blocking finding, correct
  the Phase 1–2 status, capture the current compile/test baseline, and keep
  real cash, coin power, PCA outputs, and `PHYSICAL_EVIDENCE_CONFIRMED`
  disabled.

### R0 files and evidence changed

- Moved the supplied `Bill_Acceptor.ino` into
  `hardware/references/legacy/Bill_Acceptor.ino` with an audit warning. It is
  not the integrated controller and must never be flashed.
- Added `hardware/references/legacy/README.md` and updated
  `hardware/references/README.md` with provenance and the unverified mapping.
- Synchronized `README.md`, `CLAUDE.md`, `hardware/README.md`,
  `hardware/firmware/README.md`, and
  `docs/architecture/cash-order-integration.md` so they no longer imply that
  the current simulator foundation is release-ready.
- No runtime firmware, database, daemon, or POS behavior was changed in R0.

### V1 bill sketch classification

The sketch is **unverified legacy evidence**. Its `1 pulse = ₱10` hypothesis
predicts ₱20 = 2 pulses, ₱50 = 5 pulses, and ₱100 = 10 pulses. It has no
inhibit control, payment-session binding, replay/idempotency protocol, safe
atomic shared-state handling, or measured external 4.7 kΩ interface/timing.
Its 50 ms debounce and 250 ms train gap are not calibration evidence.

### Release-blocking findings recorded for R1–R4

1. `hardware/firmware/mendo_controller/mendo_controller.ino` currently writes
   active-low PCA OE with the unsafe polarity: fail-safe LOW enables outputs,
   while movement HIGH disables them. Do not connect powered servos.
2. PCA9685 sleep/prescale/restart initialization and readback at calibrated
   50 Hz are absent.
3. Firmware emits `mapped_centavos=0`, while the current checkout ingestion
   path expects a supplied session/mapping; real bill events cannot safely
   credit an order.
4. `SerialHardwareBackend.drain_events()` destructively drains the queue and
   `HardwareDaemon` returns only its first event, so queued events can be lost.
5. EEPROM cash replay after reboot is documented but not implemented; stored
   evidence lacks the payment session required for valid replay.
6. The public cash-event route accepts caller-supplied money and can forge a
   payment; it must be removed before any network demonstration.
7. Cash-session expiry is not scheduled by a worker; an abandoned browser can
   leave acceptors active.
8. `PAY_STOP` can discard a pulse train already captured by the ISR instead of
   inhibiting and finalizing it safely.
9. Database/admin motion profiles are not sent to firmware; hardcoded
   `1500/1900 µs` values are used.
10. Multi-unit failure recovery can release unrelated reservations instead of
    only the affected undispensed unit.
11. `return_dispensed_to_stock()` calls the undefined `_set_order_states`.
12. Real cashier checkout can return before real dispensing is completed.
13. Admin recovery, profile, cashbox, refund, and reconciliation controls are
    not exposed as a complete authenticated workflow.
14. Earlier Phase 1–2 checkpoint entries are superseded: they are now
    **implemented foundation; remediation required**, not release acceptance.

### Current compile and test baseline

- `./.venv/bin/python -m pytest -q testing/test_hardware_payment.py` —
  **21 passed in 5.64s**.
- `arduino-builder -compile -hardware /usr/share/arduino/hardware -tools
  /usr/share/arduino/tools -tools /usr/share/arduino/hardware/tools
  -built-in-libraries /usr/share/arduino/hardware/arduino/avr/libraries
  -fqbn arduino:avr:uno .../hardware/firmware/mendo_controller/mendo_controller.ino`
  — **9,178 bytes flash; 1,371 bytes globals; 677 bytes free SRAM**.
- The same builder command with `-fqbn
  arduino:avr:mega:cpu=atmega2560` — **10,222 bytes flash; 1,383 bytes
  globals; 6,809 bytes free SRAM**.
- The legacy sketch built as Uno — **2,242 bytes flash; 234 bytes globals**.
- Post-R0 `./.venv/bin/python -m pytest -q` — **113 passed, 52 subtests
  passed in 38.17s**; R0 changed documentation and evidence placement only.
- Post-R0 `./.venv/bin/python -m compileall -q mendo_core pos hardware testing`
  — **exit 0**; both JavaScript `node --check` commands — **exit 0**.
- `git diff --check` — **clean** after the R0 edits.

### Hardware gate and risks

- Hardware measurements, photos, pulse captures, inhibit-polarity evidence,
  and calibration values: **none available**.
- `PHYSICAL_EVIDENCE_CONFIRMED` remains false. Real cash, coin power, PCA
  outputs, and real-mode checkout remain disabled. The Uno's reported 677-byte
  free-SRAM compile result is not accepted as a production margin; R1 must
  measure a runtime stack watermark or move to Mega.
- Rollback/recovery: preserve the legacy sketch under
  `hardware/references/legacy/`; if R1 work regresses, keep real mode disabled,
  rerun the recorded build/tests, and do not flash or power the current
  integrated firmware.

### Documentation and next action

- Synchronized: `CHECKPOINT.md`, `hardware/README.md`,
  `hardware/firmware/README.md`, `README.md`, `CLAUDE.md`,
  `docs/architecture/cash-order-integration.md`, and the legacy-reference
  notes.
- Next safe action: present this R0 evidence and obtain explicit user approval
  before beginning **R1 — Firmware safety**. No R1 code has been changed.
- User approval: **pending**.

### D-0009 — 2026-08-03, V1 bill sketch classification

The supplied root `Bill_Acceptor.ino` is unverified legacy evidence. Its
₱10-per-pulse mapping and timing constants are hypotheses only. It is retained
under `hardware/references/legacy/` and must never be flashed as the integrated
controller or used to authorize the installed TB unit.

## USB controller inspection — 2026-08-03 18:48:48 PST (+0800)

- Status: **diagnostic complete; no firmware write performed**.
- Detected board: Arduino Uno R3, USB VID/PID `2341:0043`, ATmega328P
  signature `0x1e950f`.
- Stable device path:
  `/dev/serial/by-id/usb-Arduino__www.arduino.cc__0043_751363233373514071E2-if00`
  → `/dev/ttyACM0`.
- Read-only flash inspection found the strings `MENDO_VENDO_V2:READY`,
  `SLOTS:`, `DISPENSE:`, and `System Ready`. This is an older self-test/legacy
  image, not the current integrated `mendo_controller.ino` image.
- Exact command results: `avrdude -n` identified the ATmega328P successfully;
  read-only flash dump completed successfully. No TB, coin acceptor, PCA9685,
  or servo wiring was validated by this inspection.
- Safety decision: do not flash the current integrated firmware because the R0
  audit found the PCA9685 OE polarity unsafe. The next write must be either an
  approved R1-remediated controller or a deliberately USB-only safe diagnostic
  image.
- Next safe action: obtain explicit direction on the image to flash; real cash,
  coin power, PCA outputs, and `PHYSICAL_EVIDENCE_CONFIRMED` remain disabled.

## USB-only diagnostic upload — 2026-08-03 18:53 PST (+0800)

- Status: **complete; diagnostic image only; R1 integrated firmware not started**.
- Target: Arduino Uno R3 / ATmega328P at the stable `/dev/serial/by-id/`
  path recorded above.
- Files added: `hardware/firmware/bench_safe/bench_safe.ino` and its README.
- Build result: `arduino-builder` Uno compile succeeded with **2,836 bytes
  flash and 237 bytes globals**.
- Upload result: `avrdude` wrote and verified **2,836 bytes** successfully.
- Serial command/result: at 115200 baud, `PING` returned `PONG`; startup and
  status output reported `MODE=USB_ONLY`, `ACCEPTORS=DISABLED`,
  `D5=LOW_COIN_POWER_OFF`, `D7=HIGH_PCA_OE_DISABLED`, `I2C=PCA_NOT_ACCESSED`,
  and `DISPENSING=NOT_IMPLEMENTED`.
- Safety condition: keep the TB, Allan acceptor, PCA9685, and servos
  disconnected. This image leaves D4 as `INPUT_INHIBIT_NOT_DRIVEN`; it is not
  a bill-inhibit controller and must not be used with a powered TB.
- No cash, pulse, voltage, inhibit-polarity, or servo measurement was made.
- Next safe action: approve and implement R1 before uploading any integrated
  controller. Real cash/motion and `PHYSICAL_EVIDENCE_CONFIRMED` remain off.

## Payment-only POS integration — 2026-08-05

- Status: **implemented and software-verified; ready for a supervised cash/POS
  trial; medicine motors remain disabled**.
- User evidence: the supplied combined D2/D3 diagnostic was reported working
  across the coin set. Earlier TB74 captures establish the D3 2/5/10 pulse map
  for PHP 20/50/100. The integrated controller now uses the diagnostic's tested
  D2 filters and the measured D3 filters.
- Controller gate split: `CASH_INPUTS_CONFIRMED=true` and
  `MEDICINE_MOTORS_ENABLED=false`. `DISPENSE_ONE` is rejected, and active-low
  PCA9685 OE is held HIGH during boot, fail-safe, and payment.
- Boundary fixes: controller `session` is normalized to `session_ref`; the host
  maps validated pulse counts instead of treating `mapped_centavos=0` as an
  unknown payment; queued events are retained until database commit and ACK,
  so a burst no longer loses every event after the first.
- POS behavior: both kiosk checkout and authenticated `/shop` Cashier start a
  durable cash session. On reaching the amount due,
  `finalize_payment_only_sale` deducts reserved inventory, clears reservations,
  writes sale logs, creates one receipt, and records
  `completion_mode=payment_only` in one `BEGIN IMMEDIATE` transaction. Replay
  returns the same receipt and does not deduct again. No dispense job is made.
- Verification: focused hardware/payment suite **39 passed** and the full suite
  **131 passed with 52 subtests**; simulator browser
  flow moved a PHP 10 order from `awaiting_cash` to `paid/completed`, reduced
  stock 10 → 9, left reserved stock at 0, and created a receipt; Python
  compileall, both JavaScript syntax checks, and `git diff --check` passed.
- Arduino Uno verification: **10,526 bytes flash (32%)**, **1,407 bytes globals
  (68%)**, **641 bytes free SRAM**. Frame CRC output is streamed to avoid a
  second 241-byte stack buffer during cash-event emission.
- Remaining prototype risks: controller EEPROM cash replay across a hard reset,
  acceptor-control polarity, conditioned voltage limits, and long-run/noise
  trials still require physical fault testing. `PAY_STOP` now inhibits new
  money while draining a pulse train that had already begun. Keep the trial
  supervised and do not attach medicine motors.

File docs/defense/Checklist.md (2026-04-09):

# OLDCARTS Duration Safeguard Matrix — Implementation Checklist

## Overview
Implementing the Duration component of OLDCARTS as a universal safety measure across all 9 symptom categories. When a symptom exceeds its clinically-defined duration threshold, the system blocks OTC recommendations and refers the patient to a doctor.

## Duration Safeguard Matrix

| # | Symptom | Threshold | Action | Clinical Rationale |
|---|---|---|---|---|
| 1 | FEVER | > 3 days | Block / Refer | Dengue, Typhoid, Malaria indicator |
| 2 | DIARRHEA | > 2 days | Block / Refer | Dehydration risk, bacterial/parasitic infection |
| 3 | SORE_THROAT | > 5 days | Block / Refer | Streptococcal infection risk |
| 4 | STOMACH_ACHE | > 7 days | Block / Refer | PUD, gallstones, appendicitis |
| 5 | HEADACHE | > 7 days | Block / Refer | Hypertension, neurological issues |
| 6 | BODY_ACHES | > 7 days | Block / Refer | Inflammatory arthritis, nerve damage |
| 7 | RASHES / ALLERGIC_RHINITIS | > 7 days | Block / Refer | Fungal infection, chronic immune issue |
| 8 | NASAL_CONGESTION / RUNNY_NOSE | > 10 days | Block / Refer | Bacterial sinusitis |
| 9 | COUGH (all types) | > 14 days | Block / Refer | TB screening (DOH protocol) |

## Design Decisions
- **Question Format**: Multiple choice buttons (Option A)
- **Exceeded Behavior**: Block OTC entirely — no recommendations, refer to doctor
- **Flow Order**: After existing clarification (e.g. cough type → then duration)
- **Multi-symptom**: Ask duration for each symptom separately

---

## Implementation Tasks

### Backend (mendo_core/step4_recommend.py)
- [x] Add `DURATION_THRESHOLDS` dictionary mapping symptom labels to day thresholds
- [x] Add `check_duration_safety()` function
- [x] Add `get_duration_question()` function returning per-symptom question + button options
- [x] Add duration referral response builder (doctor referral message)
- [x] Add `parse_duration_days()` for button value parsing
- [x] Add `_DURATION_OPTIONS` with bilingual button labels per symptom
- [x] Add `_SYMPTOM_DISPLAY_NAMES` for Tagalog/English question text

### API Routes (pos/routes_consultation.py)
- [x] Add `/consult/api/duration-check` POST route
- [x] Integrate duration flow into consultation state machine
- [x] Handle multi-symptom sequential duration asking (pending_durations chaining)
- [x] Add POS inventory cross-reference for final recommendation
- [x] Add interaction logging for both block and pass outcomes

### Frontend UI (web/templates/pos/consultation.html)
- [x] Add duration question display component (consistent with existing clarification UI)
- [x] Add duration button options (multiple choice)
- [x] Add doctor referral display (block screen with warning + clinical rationale)
- [x] Wire duration flow: after clarification → ask duration per symptom → proceed or block
- [x] Handle multi-symptom sequential duration questions
- [x] Add progress dots for multi-symptom duration tracking
- [x] Add CSS for `.duration-referral-banner` and `.duration-progress`
- [x] Reset duration state in `assessAgain()` and `resetAll()`

### Testing (testing/test_regressions.py)
- [x] Add tests for each symptom's duration threshold (11 blocked tests)
- [x] Test duration block behavior (no recommendations returned)
- [x] Test duration safe behavior (5 safe tests)
- [x] Test multi-symptom duration flow (chain test)
- [x] Test edge cases (exactly at threshold — 4 tests)
- [x] Test API endpoint (safe, blocked, chain, missing params — 4 tests)
- [x] Test `parse_duration_days()` (4 tests)
- [x] Test `get_duration_question()` coverage (1 test)
- [x] Test threshold count verification (1 test)

### Thesis Updates (FULL_SYSTEM_DATA_FOR_THESIS.md)
- [x] Update OLDCARTS section — now covers 5 components (Character, Onset, Aggravating, Timing, Duration)
- [x] Add Duration Safeguard Matrix table with all 13 entries
- [x] Update system architecture description (API endpoints)
- [x] Update safety measures section (Key Technical Innovations #20)
- [x] Add Tier 5 testing documentation (31 duration tests)
- [x] Update Iteration 3 description
- [x] Add OLDCARTS to Theoretical Framework

---

## Progress Log
- **Started**: March 30, 2026
- **Status**: ✅ Complete

### Test Results
- **74/74 regression tests passed** (43 original + 31 new duration tests)
- **All 3 API scenarios verified** (safe, blocked, chain)
- **Runtime**: ~13.5 seconds

### Files Modified
| File | Changes |
|---|---|
| `mendo_core/step4_recommend.py` | Added DURATION_THRESHOLDS, check_duration_safety(), get_duration_question(), parse_duration_days() |
| `pos/routes_consultation.py` | Added `/consult/api/duration-check` route with full flow logic |
| `web/templates/pos/consultation.html` | Added duration UI, CSS, JS flow, referral banner |
| `testing/test_regressions.py` | Added DurationSafeguardTests class (31 tests) |
| `FULL_SYSTEM_DATA_FOR_THESIS.md` | Updated OLDCARTS to 5 components, added Duration Matrix table, Tier 5 tests, Innovation #20 |

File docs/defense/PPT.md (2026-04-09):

# MendoVendo v3.0 — Presentation Guide & Defense Preparation

---

## PART 1: DEFENSE READINESS ANALYSIS

### What's Strong (Defense-Ready)
- **Introduction & Problem Statement** — Well-grounded: 92.6% self-medication stat, v1/v2 precision-safety gap (78.08% precision), adversarial challenge set proving v2 fails (Table 1 & 2). Panel will appreciate the concrete failure examples.
- **Literature Review** — 6 studies covering hybrid architectures, multi-symptom decomposition, knowledge graphs. Good positioning against Ada Health, Babylon Health, Isabel Healthcare.
- **System Architecture** — Very detailed 5-stage pipeline. Duration Safeguard with WHO/CDC/Mayo Clinic references [33]-[42]. OLDCARTS well-applied.
- **Comparative Benchmarking** — Honest: acknowledges transformer data-scarcity caveat, doesn't overclaim. 81.2% vs 55.9% (SVM) vs 22.6% (XLM-RoBERTa).
- **"Why Not LLM?"** section — Panel-killer. 6 strong reasons. Will save you from the "why not just use ChatGPT?" question.
- **Error-Driven Iterative Refinement** — 19 issues found and fixed. Gemini 2.5 Pro supplementary check adds credibility.
- **References** — 42 refs, all 2023-2026 range. Solid.

### Potential Gaps / Things Panel Might Flag

1. **Testing section doesn't mention the 74 regression tests** — The PDF says "structured benchmark cases, regression checks, and scenario-based safety validation" but never mentions the exact count of 74 regression tests (43 original + 31 duration). Add "74 regression tests — including 31 dedicated to the duration safeguard — all passed" to the Testing paragraph.

2. **Iteration 2 & 3 are entirely future work** — The paper is honest about this, but panelists may push: "So you only completed Iteration 1?" Be ready to explain that Iteration 1 is a fully functional, tested artifact — not a prototype — and that Iterations 2-3 are validation/deployment phases requiring ethical clearance.

3. **No real-user data yet** — The 80-case "real-user simulation" was researcher-constructed, not from actual pharmacy users. Panel will catch this. Defense: "This is why Iteration 2 exists — controlled field deployment to collect real data. The simulation was designed to stress-test the pipeline before exposing it to real users."

4. **Dataset size is small** — 288 benchmark cases, 331 dictionary phrases, 24 medicines. Panel may ask if this is enough. Defense: This is a bounded problem (13 symptoms, 24 medicines) — not open-ended. The dictionary covers the actual language people use in Davao pharmacies. Iteration 2 will expand from real consultation data.

5. **No pharmacist validation yet** — The ASG framework is a workaround. "Pharmacist review remains part of Iteration 2." Be transparent about this.

6. **The "gi ubo ko" scenario is now in the paper but the diarrhea scenario appears to have been removed** — Your OLDCARTS Sample Implementation only shows the cough scenario. If the diarrhea example was in an earlier draft, make sure it's still there or be ready to walk through it verbally.

---

## PART 2: SYSTEM ARCHITECTURE SLIDES — WHAT TO PUT & WHAT TO SAY

---

### SLIDE: System Architecture Overview

**Put on slide:**
```
MendoVendo v3.0 — 5-Stage Hybrid Pipeline

User Input (Bisaya/Tagalog/English)
         │
    ┌────▼────┐
    │ Stage 0 │  Triage / Red-Flag Safety Layer
    └────┬────┘
         │ (pass if no emergency)
    ┌────▼────┐
    │ Stage 1 │  Dictionary-Based Symptom Extraction
    └────┬────┘  331 phrases × 13 labels × 5 languages
         │
    ┌────▼────┐
    │ Stage 2 │  Semantic Embedding Fallback
    └────┬────┘  MiniLM-L12-v2 (33M params, 384-dim)
         │      only activates if Stage 1 finds nothing
    ┌────▼────┐
    │ Stage 3 │  Hybrid Merge + Lexical Guards + Safety Filters
    └────┬────┘  Negation, red-flag suppression, cough-type tree
         │
    ┌────▼────┐
    │ Stage 4 │  OLDCARTS Clarification + Duration + Recommendation
    └─────────┘  24 medicines, ASG dataset, age/safety filtering
```

**What to say:**
> "MendoVendo v3.0 uses a five-stage pipeline that separates symptom detection from recommendation. This is the key design shift from v2 — instead of directly matching text to drugs, we first figure out what the user's symptoms are, then we decide what medicine is appropriate under safety constraints. Each stage is modular and independently testable. The pipeline processes multilingual input — Bisaya, Tagalog, English, code-switching, even Jejemon — and applies safety checks at every level."

---

### SLIDE: Stage 0 — Triage / Red-Flag Safety Layer

**Put on slide:**
```
Stage 0: Red-Flag Triage
━━━━━━━━━━━━━━━━━━━━━━

Method: Proximity-Based Co-occurrence + Exclusion Tokens

┌───────────────────┬─────────────────────────┬───────────────────┐
│ Red Flag          │ Trigger Pattern         │ Exclusion Tokens  │
├───────────────────┼─────────────────────────┼───────────────────┤
│ GI Hemorrhage     │ [blood] + [stool/vomit] │ —                 │
│ Cardiac Emergency │ [pain] + [chest]        │ cough, plema, ubo │
│ Respiratory       │ [difficulty] + [breath] │ —                 │
│ Dengue Warning    │ [fever] + [rashes]      │ bite, allergy     │
│ Stroke            │ [numb] + [face/half]    │ tooth, ngipin     │
│ Severe Dehydration│ [diarrhea] + [no urine] │ —                 │
│ Pregnancy Block   │ [buntis/pregnant]       │ asawa, sister     │
│ Hyperthermia      │ [fever] + [40-42°C]     │ kilo, years old   │
│ Direct Emergency  │ seizure / fainted       │ —                 │
└───────────────────┴─────────────────────────┴───────────────────┘

→ If triggered: BLOCK all OTC. "Consult a licensed medical expert."
→ If not triggered: proceed to Stage 1.
```

**What to say:**
> "Before anything else, Stage 0 screens for emergencies. It uses co-occurrence detection — it looks for specific word combinations within a lexical window. For example, 'blood' near 'stool' triggers GI hemorrhage. But the critical design here is the exclusion tokens. Without them, someone saying 'masakit dibdib ko dahil sa ubo' — chest hurting from coughing — would get flagged as a cardiac emergency and blocked from getting cough medicine. The exclusion tokens prevent that false alarm. Same with 'high blood pressure' — the word 'blood' alone won't trigger GI bleeding because the pattern requires a stool or vomit word nearby."

**They might ask:**
- **Q: "What if someone has a real chest pain emergency but also mentions coughing?"**
  > A: "The exclusion tokens only suppress the cardiac flag when cough-related words are the ONLY context around 'chest pain.' If someone says 'masakit ang dibdib ko, nahihirapan huminga' — chest pain with difficulty breathing — the respiratory emergency flag triggers independently, and the system still blocks OTC. The exclusion is narrow, not blanket."

- **Q: "How did you decide on these red-flag categories?"**
  > A: "The nine categories were selected based on WHO emergency triage guidelines and common pharmacy-walk-in scenarios in the Philippine context. We prioritized conditions where giving OTC medicine could mask a serious problem — like fever plus rashes hiding dengue, or diarrhea with no urination indicating severe dehydration."

- **Q: "What about the pregnancy exclusion — 'asawa, sister'? Why exclude those?"**
  > A: "In Filipino pharmacies, people commonly buy medicine for family members. Someone saying 'buntis ang asawa ko, may lagnat siya' — my pregnant wife has a fever — is purchasing for a proxy. The system should recommend fever medicine for the wife, not block the consultation entirely because it detected the word 'pregnant.'"

---

### SLIDE: Stage 1 — Dictionary-Based Symptom Extraction

**Put on slide:**
```
Stage 1: Dictionary Extraction
━━━━━━━━━━━━━━━━━━━━━━━━━━━

331 phrases → 13 symptom labels → 5 language variants

Processing Pipeline:
1. Text Normalization
   - lowercase, leetspeak decode (s@k1t → sakit), whitespace collapse
   
2. Cough-Type Decision Tree (7-step)
   - Dry vs Productive vs General before main scan
   
3. Phrase Matching
   - Multi-word: substring match
   - Single-word: regex word-boundary (\b)
   
4. Negation Handling
   - 11-word negation lexicon (Tag/Bis/Eng)
   - 0-2 word proximity window
   - Consumed negation logic
   - Contrastive boundary splitting (pero, but, kaso)
   
5. Fuzzy Rescue
   - Levenshtein distance for misspellings (7 families)
   - Exclusion sets to prevent false rescues
```

**What to say:**
> "Stage 1 is the workhorse — it handles the vast majority of detections. It's a handcrafted dictionary of 331 phrases covering Tagalog, Bisaya, English, Taglish, and Jejemon. The design is precision-first: we'd rather miss a symptom than detect a wrong one, because a false positive in medicine recommendation is more dangerous than a false negative. Key features: the cough decision tree runs BEFORE the main scan so we can distinguish dry from productive cough early. The negation handler catches 'wala akong lagnat' — I don't have fever — using a proximity window. And the fuzzy rescue recovers typos like 'laganat' for 'lagnat' using Levenshtein distance, but with exclusion sets — 'ubo' has a distance-1 exclusion for 'ulo' so we don't confuse cough with headache."

**They might ask:**
- **Q: "Why not just use the semantic model for everything? Why maintain 331 phrases manually?"**
  > A: "Two reasons. First, the dictionary is deterministic — if I type 'ubo,' I know with 100% certainty it maps to COUGH. No probability, no threshold tuning. That matters for safety-critical recommendations. Second, performance: dictionary lookup is essentially instant. The semantic model takes ~93ms per query. On a Raspberry Pi serving walk-in customers, that difference matters."

- **Q: "How did you build the 331 phrases? Is it comprehensive enough?"**
  > A: "We started from clinical references and MIMS Philippines symptom descriptions, then expanded it through fieldwork — observing how people actually describe symptoms at pharmacies in Davao City. The real-user simulation showed 90% exact match, with the 10% gap coming from severe misspellings and dual cough-type mentions. Iteration 2 will expand the dictionary from actual consultation logs."

- **Q: "How does 'consumed negation' work exactly?"**
  > A: "If someone says 'walang lagnat pero masakit ulo' — no fever but headache — the negation word 'walang' is consumed by the first symptom it negates (lagnat/fever). It doesn't carry over to 'masakit ulo' (headache) after the contrastive boundary 'pero.' Each segment is evaluated independently."

---
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

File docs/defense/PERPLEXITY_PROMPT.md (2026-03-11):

    # PROMPT FOR PERPLEXITY — FIX MY THESIS METHODOLOGY CHAPTER

    Copy-paste everything below this line to Perplexity:

    ---

    ## TASK

    I need you to rewrite/fix my thesis **Materials & Methods chapter** for my undergraduate CS thesis. My current methodology chapter has factual errors — it describes things the system does NOT actually do. I'm giving you:

    1. **My current methodology text** (with errors marked)
    2. **The FULL actual system data** (verified from source code)

    Please rewrite the complete methodology chapter to accurately reflect what the system actually does. Keep the academic tone, APA format, and structure of a CS thesis. Keep relevant citations. Remove all false claims.

    ---

    ## MY THESIS INFO

    - **Title:** MendoVendo v3.0: An AI-Enabled Multilingual OTC Medicine Recommendation System for Philippine Pharmacies  
    - **Degree:** Bachelor of Science in Computer Science
    - **Methodology Type:** Design Science Research (DSR)
    - **System Type:** Hybrid NLP pipeline for symptom extraction and OTC medicine recommendation
    - **Target Deployment:** Raspberry Pi 5-based physical dispensing kiosk

    ---

    ## ERRORS IN MY CURRENT METHODOLOGY (MUST FIX)

    ### Error 1: Wrong symptom count
    - ❌ CURRENT: "15 clinically meaningful symptom labels" including NAUSEA, VOMITING, DIZZINESS, FATIGUE
    - ✅ CORRECT: **13 symptom labels**: HEADACHE, FEVER, COUGH_DRY, COUGH_PRODUCTIVE, COUGH_GENERAL, RUNNY_NOSE, NASAL_CONGESTION, SORE_THROAT, STOMACH_ACHE, DIARRHEA, BODY_ACHES, ALLERGIC_RHINITIS, RASHES. No NAUSEA, VOMITING, DIZZINESS, or FATIGUE.
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

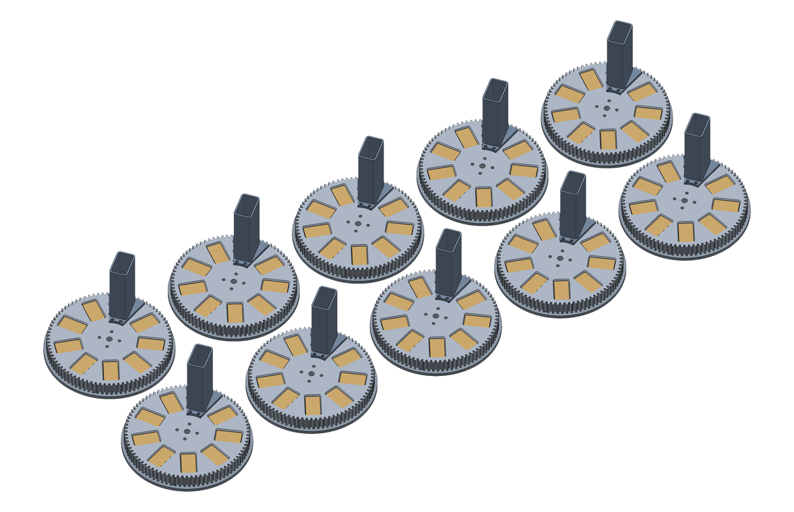
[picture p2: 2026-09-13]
docs/hardware-figures/a05_ten_slot_bank.png

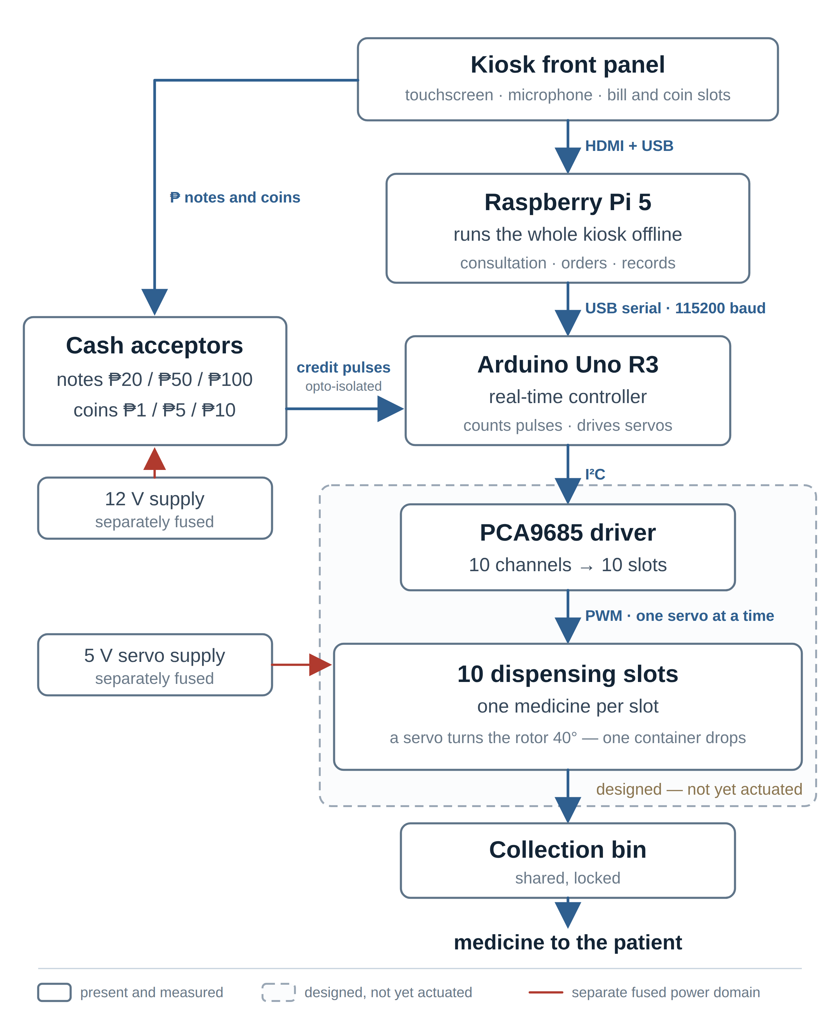
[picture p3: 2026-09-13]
docs/hardware-figures/s01_system_simple.png

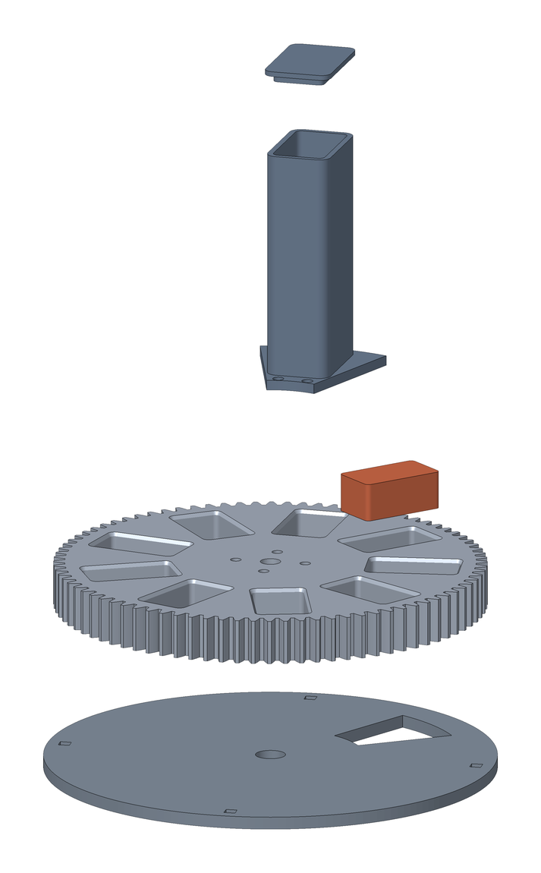
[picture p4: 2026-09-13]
docs/hardware-figures/a03_slot_exploded.png

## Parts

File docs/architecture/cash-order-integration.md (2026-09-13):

# Cash order and dispenser architecture

Status: payment-only real cash path implemented for supervised POS testing;
medicine-motor dispatch is intentionally disabled.

## Durable boundary

The browser cart is only a pre-order view. `OrderService` creates the durable
order, snapshots each catalog line and centavo price, and reserves stock under
SQLite `BEGIN IMMEDIATE`. Availability is `stock_quantity - reserved_quantity`.
The order reference and idempotency key are the recovery handles; browser
sessions are not the payment source of truth.

Cash events carry the payment session, source, raw pulse count, mapped
centavos, controller boot id, and sequence number. The unique event id and
boot/sequence/source constraint make replay safe. Unknown pulse trains credit
nothing and put the order into manual review. When payment reaches the due
amount, overpayment is stored separately from medicine revenue and acceptors
are stopped.

In the current payment-only rollout, reaching the amount due calls
`finalize_payment_only_sale`. It deducts all reserved quantities, releases the
reservations, writes stock logs, creates the receipt, and stamps
`completion_mode=payment_only` in one SQLite write transaction. Replaying that
transition returns the same receipt and cannot deduct stock again. No dispense
job is created and no item is labelled physically dispensed.

The older sequential dispense state machine remains isolated for future motor
work, but checkout does not invoke it in this phase.

Polling an already-paid order is also a recovery trigger after a Flask restart:
it re-enters the idempotent stock/receipt commit and never contacts a motor.

## Hardware process boundary

Flask uses `HardwareService` and a short-lived Unix-socket client. A dedicated
`hardware.daemon` owns the socket and, in real mode, the only `/dev/mendo-uno`
serial descriptor through `SerialHardwareBackend`. Frames are bounded,
newline-delimited ASCII with request ids and CRC16-CCITT. The simulator is the
default development mode and is labelled in every status/order response.

Real cash requires the expected firmware identity, protocol-version match,
recent heartbeat, healthy connection, and the measured cash-input gate. The
controller sends `session`; the serial owner normalizes it to `session_ref` and
maps clean pulse counts through `PulseMapping`. Events are peeked until the POS
commits and ACKs them, so a burst is not destructively drained. Motion stays
behind the separate false compile-time gate.

## Recovery ownership

| Evidence/state | Durable owner | Recovery rule |
| --- | --- | --- |
| Cash pulse | `cash_events` + controller EEPROM | Commit, then ACK; replay is duplicate-safe |
| Payment amount | `orders` | Integer centavos; overpayment is separate |
| Stock reservation | `inventory.reserved_quantity` + `order_items` | Release only undispensed units |
| Physical attempt | `dispense_jobs` + controller job ring | Never retry an unknown physical result |
| Receipt | legacy `transactions` projection | Create once with the payment-only stock commit |
| Drawer count | `cashbox_sessions` | Reconcile only events assigned to that drawer session |

The physical acceptance evidence remains a later action: exact TB model and
PHP sheet, harness continuity, DIP polarity, coin/bill pulse captures,
0–5 V conditioned signals, servo profiles, current/voltage measurements, and
the required repeated trial counts.

The authenticated admin boundary exposes the same durable evidence through
hardware health, payment-event, dispense-job, accounting, cashbox, profile,
and manual-recovery endpoints. Sales revenue is reported separately from
received tender and overpayment.

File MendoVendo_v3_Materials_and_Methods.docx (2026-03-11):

# CHAPTER 3

# MATERIALS AND METHODS

## 3.1 Introduction

This chapter describes the research methodology used to develop MendoVendo v3.0, an AI-enabled multilingual symptom detection and over-the-counter (OTC) medicine recommendation system built for deployment on resource-constrained edge devices. The study follows a Design Science Research (DSR) methodology organized into two iterative design cycles. The first iteration covers the complete system design, implementation, and evaluation against safety, precision, and multilingual robustness criteria. The second iteration focuses on expert validation and targeted refinement based on evaluation findings.

The research uses a hybrid rule-based and distributional semantics approach that balances semantic understanding with computational efficiency and clinical safety. This chapter covers the research design, theoretical framework, system architecture, data construction, evaluation methodology, and the iterative refinement process that shaped the final system.

The main research objective is to develop a system that reduces safety violations while improving recommendation precision on clinically meaningful outputs, without sacrificing recall on supported symptom vocabulary. The system achieves this through a five-stage cascaded hybrid NLP pipeline that combines deterministic rule-based extraction, pre-trained multilingual sentence embeddings, lexical safety guards, a triage layer for medical emergencies, and a structured medicine dataset grounded in authoritative pharmaceutical sources.

## 3.2 Research Design

This study uses an iterative design science research methodology, which is well suited for developing and evaluating artificial intelligence systems in healthcare contexts (Engstrom et al., 2022; Baskerville et al., 2024). Design science research offers a systematic framework for creating and evaluating novel artifacts, in this case a hybrid NLP pipeline and recommendation engine, through iterative cycles of design, implementation, and evaluation. The methodology consists of two design iterations: the first produces the complete working system, and the second focuses on expert validation and refinement based on evaluation outcomes.

### 3.2.1 Iteration 1: Complete System Design, Implementation, and Evaluation

The first iteration encompasses the full design, implementation, and evaluation of the MendoVendo v3.0 system. This iteration begins with baseline analysis of MendoVendo v2.0, proceeds through the construction of all five pipeline stages, and concludes with comprehensive evaluation and error-driven refinement. Key activities include:

Phase 1A: Baseline Analysis and Architecture Design

- Baseline System Evaluation: Reproduction and systematic evaluation of the existing TF-IDF and cosine similarity-based approach from v2.0, confirming strong recall but low precision and multiple safety-critical errors on adversarial examples (e.g., negated symptoms being treated as positive detections).
- Symptom Taxonomy Definition: Establishment of 13 clinically meaningful symptom labels (HEADACHE, FEVER, COUGH_DRY, COUGH_PRODUCTIVE, COUGH_GENERAL, RUNNY_NOSE, NASAL_CONGESTION, SORE_THROAT, STOMACH_ACHE, DIARRHEA, BODY_ACHES, ALLERGIC_RHINITIS, and RASHES), covering the most common OTC-treatable conditions in Philippine pharmacy settings. COUGH_GENERAL serves as an ambiguous intermediate label triggering a clarification prompt when it is the sole detected symptom.
- Pipeline Architecture Design: Specification of the five-stage cascaded pipeline with (0) triage/red-flag safety layer, (1) rule-based dictionary extraction, (2) semantic embedding fallback, (3) hybrid merge with lexical guards and safety filters, and (4) structured medicine dataset scoring with safety checks.
- Requirements Gathering: Identification of functional and non-functional requirements based on v2.0 limitations, including multilingual support (English, Filipino/Tagalog, Cebuano/Bisaya, Taglish code-switching, and Jejemon/leetspeak), computational constraints for Raspberry Pi 5 deployment, and safety-critical handling of negated symptoms and medical emergencies.

Phase 1B: Dictionary Construction and Negation Engineering

- Multilingual Symptom Dictionary Construction: Iterative expansion of the rule-based symptom dictionary to 307 curated phrases across 13 symptom labels, covering five language variants: Tagalog, Bisaya/Cebuano, English, Taglish/Conyo code-switching, and Jejemon/leetspeak. Each phrase was manually verified for linguistic accuracy and clinical relevance.
- Negation Handling Implementation: Development of a comprehensive negation detection system incorporating 11 negation words (hindi, walang, walay, waley, dili, di, wala, hnd, no, not, without), a 0–2 word proximity window, consumed negation logic using 28 intervening symptom words, and negated-label tracking to prevent fuzzy rescue from re-adding negated symptoms.
- Contrastive Boundary Logic: Implementation of contrastive-boundary splitting on conjunctions (pero, but, kaso, however, though), enabling per-segment negation evaluation. A positive mention after a contrastive boundary overrides prior negation (e.g., "wala akong lagnat pero masakit ang ulo" correctly detects HEADACHE while negating FEVER).
- Fuzzy Rescue Development: Construction of seven Levenshtein-distance rescue families with curated exclusion sets to prevent false positives (e.g., "tubo" excluded from matching "ubo" for COUGH; "pantalon" excluded from matching "pantal" for RASHES). All fuzzy rescues check the negated-labels set before adding a symptom.
- Cough-Type Qualification Logic: Design of a seven-step decision tree for cough classification: (1) itchy/scratchy throat → COUGH_DRY, (2) chest-rattle/congestion indicators → COUGH_PRODUCTIVE bypass, (3) cough word presence check, (4) cough negation with plema-filler exemption, (5) dry qualifier check, (6) wet qualifier check, (7) default to COUGH_GENERAL.
- Proximity-Based Heuristic Development: Implementation of headache detection (head_word + pain_word within ≤5 tokens), sore throat proximity (throat_word + pain_word within ≤5 tokens with dual negation checking), per-cue-group nasal inference (three independent cue groups with independent negation), and allergen-trigger inference (RASHES + allergen keyword → ALLERGIC_RHINITIS co-detection).

Phase 1C: ASG Framework and Medicine Dataset

- ASG Framework Adoption: Adoption of the Authoritative-Source-Grounded (ASG) framework for medicine data, sourcing all drug information from package inserts, MIMS Philippines, and DOH Philippines guidelines. This approach replaced the originally planned pharmacist annotation process (via web tool at mendo.diapana.dev), which could not be completed within the project timeline. The ASG framework ensures every medicine recommendation is traceable to an authoritative pharmaceutical source.
- Medicine Dataset Construction: Assembly of 23 OTC medicine entries (18 unique brands) with 15 fields each, including 7 ASG-specific fields (approved indications, indication source, contraindications, warnings, drug interactions, maximum duration, contraindication source). This scope was intentionally reduced from v2.0's 81 entries to focus exclusively on OTC medications appropriate for kiosk dispensing.
- Recommendation Engine Development: Implementation of the rule-based symptom-to-medicine matching algorithm with score ranking, brand merging, triage gate, COUGH_GENERAL defer strategy, paracetamol overlap detection, and opposing mechanism warnings.

Phase 1D: Semantic Integration and Safety Hardening

- Semantic Fallback Integration: Integration of the pre-trained paraphrase-multilingual-MiniLM-L12-v2 sentence embedding model (approximately 33 million parameters, 384-dimensional embeddings) as a fallback layer that activates only when the dictionary-based extractor returns zero symptoms. The model is used in inference-only mode with no fine-tuning, ensuring reproducibility and eliminating overfitting risk. A total of 118 anchor sentences (8–12 per label) serve as gold-standard semantic reference points, with a fixed cosine similarity threshold of 0.65 determined through empirical testing.
- Lexical Guard Mechanism: Development of 11 keyword gates that require each semantic detection to be grounded in at least one relevant keyword from the original input text. This prevents the embedding model from hallucinating symptoms not lexically present in the user's description (e.g., blocking COUGH detection when no cough-related word appears).
- Triage/Red-Flag Safety Layer: Implementation of an eight-category medical emergency detection system using multilingual regular expressions covering chest pain, difficulty breathing, blood in stool, vomiting blood, severe allergic reaction, high fever (≥40°C), seizure, and loss of consciousness. The triage layer uses light normalization (lowercase and whitespace only) to preserve digit values critical for temperature detection. When triggered, the recommendation engine suppresses all OTC suggestions and advises "CONSULT A DOCTOR."
- Centralized Semantic Safety Filters: Implementation of seven explicit negation functions (for fever, headache, cough, diarrhea, sore throat, nasal symptoms, and allergy) plus red-flag suppression rules (blood_in_stool suppresses DIARRHEA; severe_allergic_reaction suppresses SORE_THROAT) in a centralized safety filter applied to all semantic detections.

Phase 1E: Evaluation and Error-Driven Refinement

- Benchmark Construction: Creation of a 288-case structured test benchmark organized across 60 test categories and four evaluation tiers (Functional, Robustness, Adversarial, Safety), with CSV-based test specification including input text, expected age, cough type, expected symptoms, and category annotations.
- Error-Driven Iterative Refinement: Systematic adversarial probing uncovered 19 bugs across the pipeline, each fixed and regression-tested against the full 288-case benchmark. Bug categories include: negation bypass errors, cough-type misclassification, false positive triggers from substring matching, fuzzy rescue collisions, contrastive boundary edge cases, and semantic hallucination in the absence of lexical grounding.
- Comprehensive Evaluation: Final evaluation across three benchmark sets: 288-case structured benchmark (288/288 exact match, F1 = 1.000), 9-case semantic stress test (9/9 exact match), and 80-case real-user simulation (72 exact, 8 partial, 0 failures). Combined result: 369/377 exact matches (97.9%), zero failures.
- External AI Audit: Independent validation using Gemini 2.5 Pro, which identified 7 potential improvement areas; 6 of 7 suggestions were already implemented in the system, confirming comprehensive coverage.
- Interaction Logging Implementation: Integration of a structured interaction logging system that records every consultation to a persistent JSON-Lines log file (logs/interactions.jsonl). Each log entry captures the user's raw input text, extracted symptoms, extraction source (dictionary or semantic), red-flag triggers, pipeline stage details, recommended medicines, and any cough-type clarification. This interaction log serves as the primary data source for domain-expert annotation and validation in Iteration 2. The logger is designed to be non-blocking: logging failures never interrupt the user-facing consultation flow.
- Deployment Preparation: Performance profiling and optimization for real-time inference on Raspberry Pi 5 hardware, with lazy model loading to minimize startup time and CPU-safe inference configuration.

Iteration 1 produces the complete working system with the five-stage pipeline, comprehensive safety mechanisms, ASG-grounded medicine dataset, interaction logging for expert validation, and deployment-ready architecture achieving 369/377 (97.9%) accuracy across all benchmark sets with zero failures.

### 3.2.2 Iteration 2: Expert Annotation, Validation, and Refinement (Planned)

The second iteration focuses on domain-expert validation of the system's real-world performance using the interaction logs collected during Iteration 1 deployment. While automated benchmarks confirmed strong performance (369/377 exact matches, 97.9%, zero failures), expert human validation provides additional evidence of clinical appropriateness that automated metrics alone cannot capture. Iteration 2 follows a deployment-then-expert-validation design, which is a recognized methodology in applied NLP and clinical informatics research (Li et al., 2022).

Phase 2A: Expert Annotation of Logged Interactions

- Annotator Recruitment: Licensed pharmacists or pharmacy interns will be recruited as domain-expert annotators to review the consultation logs recorded during Iteration 1 deployment. A minimum of two independent annotators per interaction is targeted to enable inter-annotator agreement analysis.
- Annotation Protocol: Each annotator independently reviews the logged interactions and evaluates three dimensions: (1) Symptom Extraction Correctness, meaning whether the system correctly identified the symptoms described in the user's input (precision and recall at the label level); (2) Recommendation Appropriateness, meaning whether the suggested OTC medicines are clinically suitable for the detected symptoms; and (3) Missed Symptoms, meaning whether any symptoms present in the input were not detected by the system (false negatives). Annotators mark each dimension on a binary correct/incorrect scale with an optional free-text comment field for additional observations.
- Inter-Annotator Agreement: Cohen's Kappa will be computed between annotator pairs to quantify agreement reliability. A Kappa value of 0.61 or above (substantial agreement) is targeted as the minimum threshold for considering the annotations valid (McHugh, 2022). Disagreements will be resolved through adjudication discussion between annotators.

Phase 2B: Analysis and System Refinement

- Expert-Validated Accuracy Metrics: Computation of expert-validated precision, recall, and F1 scores for symptom extraction based on annotator judgments, complementing the automated benchmark results from Iteration 1. These metrics provide ecological validity by evaluating performance on genuine user interactions rather than synthetic test cases.
- Error Pattern Analysis: Systematic categorization of annotator-identified errors to determine whether failures cluster around specific symptom labels, language variants, or input patterns. This analysis informs targeted refinement of the dictionary, anchor sentences, or heuristic rules.
- Recommendation Appropriateness Audit: Aggregation of annotator judgments on recommendation quality to produce a clinical appropriateness rate, which is the percentage of recommendations deemed suitable by domain experts. This metric directly addresses the safety-critical nature of OTC medicine recommendation.
- Targeted System Refinement: Based on the expert-identified error patterns, targeted improvements may include dictionary expansion for under-detected symptoms, anchor sentence additions for semantic coverage gaps, heuristic rule adjustments, or medicine dataset updates. All refinements are regression-tested against the full 288-case benchmark to prevent degradation.

Phase 2C: Additional Enhancements (Scope-Dependent)

- Partial Match Resolution: Investigation of the 8 partial matches from the 80-case real-user simulation to determine whether dictionary expansion, anchor sentence additions, or heuristic adjustments can improve detection of secondary symptoms in ambiguous multi-symptom descriptions.
- Expanded Medicine Coverage: Expansion of the medicine dataset beyond the current 23 entries based on pharmacy partner feedback and dispensing patterns observed in the interaction logs.
- Additional Symptom Coverage: Expansion of the symptom taxonomy beyond the current 13 labels to include conditions such as nausea, dizziness, and fatigue, pending identification of appropriate OTC medications for each new label.

Iteration 2 is planned as the validation and refinement cycle that bridges automated evaluation with human expert judgment. By annotating real interaction logs rather than synthetic test cases, Iteration 2 provides ecological validity and clinical confidence in the system's recommendations. The scope and priorities of Phase 2C will be informed by the annotation findings and panel evaluation recommendations.

### 3.2.3 Research Philosophy

This research adopts a pragmatic research philosophy, which prioritizes practical problem-solving over adherence to a single epistemological stance. Pragmatism is appropriate for applied AI system development in healthcare, where the research question demands both technical rigor and real-world applicability. The pragmatic approach permits the combination of rule-based deterministic methods (aligned with rationalism) and data-driven embedding models (aligned with empiricism) within a single system, unified by the practical criterion of whether the combined approach produces safe, accurate, and interpretable clinical recommendations.

## 3.3 Theoretical Framework

Unlike MendoVendo v1 and v2, which were grounded in Information Retrieval (IR) Theory due to their TF-IDF retrieval architecture, MendoVendo v3.0 transitions to a hybrid theoretical basis aligned with its new cascaded pipeline architecture. The system draws from three complementary theoretical foundations.

### 3.3.1 Rule-Based NLP and Computational Linguistics Theory

Stage 1 of the pipeline uses explicit dictionaries, regular expressions, negation windows, and cough-type disambiguation rules to encode domain knowledge as deterministic linguistic patterns. This approach is grounded in rule-based natural language processing theory, which holds that well-defined linguistic rules can capture regularities in language use with full transparency and predictability (Jurafsky & Martin, 2024).

The rule-based component draws from established practices in clinical NLP systems where deterministic pattern matching provides interpretability, auditability, and safety guarantees, all of which are critical requirements for healthcare decision support systems (Eguia et al., 2024). The system extends classical rule-based NLP with several new mechanisms: consumed negation tracking (preventing negation from propagating past intervening symptom words), contrastive boundary splitting (evaluating negation independently across discourse segments), and fuzzy rescue with exclusion sets (Levenshtein-distance matching with curated false-positive prevention).

### 3.3.2 Distributional Semantics Theory

Stage 2 uses the paraphrase-multilingual-MiniLM-L12-v2 pre-trained sentence embedding model and cosine similarity to handle paraphrased and code-switched symptom expressions that fall outside the dictionary's coverage. This component is grounded in distributional semantics theory, which assumes that words and phrases occurring in similar contexts tend to carry similar meanings (Reimers & Gurevych, 2019; Wang et al., 2021).

The distributional hypothesis, operationalized through modern neural sentence encoders (Gao et al., 2022), allows the system to recognize semantic similarity between utterances even when they use different vocabulary or syntax. This is important for handling the linguistic diversity of Philippine pharmacy interactions, where patients may describe symptoms using Tagalog, Bisaya/Cebuano, English, or code-switched combinations with creative spelling (Jejemon/leetspeak). The model is used in inference-only mode without fine-tuning, relying on its pre-trained multilingual knowledge across 50+ languages. This design choice ensures reproducibility, eliminates overfitting risk, and takes advantage of the model's broad multilingual coverage including Filipino and Cebuano.

### 3.3.3 Knowledge-Based Expert Systems Theory

Stage 4 scores candidate OTC drugs using a structured medicine dataset that encodes symptom-drug relationships, age limits, contraindications, warnings, drug interactions, and maximum safe duration. This component draws from knowledge-based expert systems theory, which structures domain expertise as formal rules and data that can be systematically applied and audited (Musen et al., 2021).

The structured dataset approach is similar to modern clinical decision support systems, where explicit encoding of medical knowledge enables deterministic safety checking and explainable recommendations (Habehh & Gohel, 2021). The system implements the Authoritative-Source-Grounded (ASG) framework, where every medicine entry's 15 fields are sourced from package inserts, MIMS Philippines, and DOH Philippines guidelines, ensuring traceability and clinical defensibility of all recommendations.

### 3.3.4 Theoretical Justification for Hybrid Architecture

These three theoretical foundations work together to justify the cascaded design. Deterministic rules handle cases where patient safety demands explicit guarantees and clear decision logic. Distributional semantics picks up paraphrased and code-switched language that no dictionary could reasonably list in advance. Finally, the structured knowledge base captures pharmaceutical expertise that needs authoritative sourcing and easy auditability.

This hybrid approach marks a deliberate shift away from the pure Information Retrieval strategy used in v1 and v2. The earlier approach struggled in three respects: IR could not generalize to unseen Bisaya or code-switched variants, TF-IDF could not tell apart "I have a headache" from "I don't have a headache," and cosine similarity on its own produced too many false positives in a medical context where incorrect recommendations carry real risk.

## 3.4 Conceptual Framework

While Section 3.5 describes the technical architecture of MendoVendo v3.0, this section presents the conceptual framework that maps the abstract relationships among the research variables. The framework identifies three categories of variables and shows how they interact to produce the study's intended outcome.

Independent Variable. The primary input to the system is the multilingual free-text symptom description provided by the user. This input may arrive in Bisaya, Tagalog, English, Taglish or Conyo code-switching, or informal orthographies such as Jejemon and leetspeak. The linguistic diversity and informality of these inputs represent the core challenge that the system must address.

Process Variable. The hybrid NLP pipeline serves as the mediating process that transforms the independent variable into a structured recommendation. Conceptually, this process involves five steps:

1. Triage screening filters emergency cases before any further processing takes place.
2. Rule-based dictionary extraction attempts deterministic symptom matching against a curated multilingual phrase bank.
3. Semantic similarity fallback activates only when the dictionary produces zero matches, using pre-trained multilingual sentence embeddings to handle paraphrased or unseen expressions.
4. Hybrid safety orchestration consolidates detected symptoms, applies keyword gates and negation checks, and ensures that deterministic results always take precedence over probabilistic ones.
5. Scored recommendation ranks OTC medicines against the validated symptom set while enforcing age, contraindication, and overlap rules.

Dependent Variable. The output of the system is the ranked OTC medicine recommendation, accompanied by safety warnings and professional-consultation advisories where appropriate. The quality of this output is measured through accuracy, precision, recall, and F1-score across the 288-case benchmark test suite and, in Iteration 2, through expert annotation of logged field interactions.

Moderating Variables. Three contextual factors influence how the process variable converts input into output: (a) language diversity, which determines whether the dictionary or the semantic fallback path is activated; (b) safety constraints, including red-flag detection and negation handling, which can override or suppress a recommendation entirely; and (c) patient context, specifically age and severity, which adjusts the scoring and filtering of candidate medicines.

Taken together, the conceptual framework positions MendoVendo v3.0 as an input-process-output system in which a linguistically diverse independent variable is transformed by a hybrid NLP process into a safety-screened dependent variable, with language diversity, safety constraints, and patient context acting as moderating variables that shape the transformation at each stage.

## 3.5 System Architecture

MendoVendo v3.0 uses a five-stage cascaded architecture running on a Raspberry Pi 5-based kiosk with an Arduino Mega for dispensing control. The architecture favors deterministic rule-based processing for speed and auditability, while keeping pre-trained multilingual sentence embeddings available as a semantic fallback for inputs the dictionary has not seen before. The system is written in Python 3.12.3 on the Flask web framework, and the core NLP pipeline is organized into four source modules totaling roughly 2,880 lines of code.

### 3.5.1 Stage 0: Triage / Red-Flag Safety Layer

The first processing stage screens user input for medical emergencies that require professional intervention rather than OTC self-medication. The triage layer detects eight categories of red-flag conditions using multilingual regular expressions:

Category | Example Triggers | Clinical Rationale
Chest Pain | "masakit ang dibdib", "chest pain", "sakit sa dughan" | Possible cardiac event
Difficulty Breathing | "hirap huminga", "shortness of breath", "lisod ginhawa" | Respiratory emergency
Blood in Stool | "may dugo sa dumi", "bloody stool" | Gastrointestinal hemorrhage
Vomiting Blood | "nagsusuka ng dugo", "vomiting blood" | Upper GI bleed
Severe Allergic Reaction | "namamaga ang lalamunan", "swollen throat" | Anaphylaxis risk
High Fever (≥40°C) | "lagnat na 41 degrees", "fever of 40" | Dangerous hyperthermia
Seizure | "seizure", "kombulsyon", "atake" | Neurological emergency
Loss of Consciousness | "nahimatay", "fainted", "nawalan ng malay" | Requires medical evaluation

A critical design decision in the triage layer is the use of light normalization (lowercase and whitespace collapsing only) rather than the full de-leetspeak normalization used in Stage 1. This preserves digit characters essential for temperature detection. The full normalization would convert "40 degrees" to "ao degrees," destroying the numerical pattern required for high-fever detection.

The triage layer does not short-circuit the pipeline; symptoms are still extracted for diagnostic logging and benchmark validation. The triage gate activates at Stage 4 to suppress OTC recommendations and return an emergency referral message.

### 3.5.2 Stage 1: Dictionary-Based Symptom Extraction

The primary extraction stage uses a curated multilingual symptom dictionary containing 307 phrases across 13 symptom labels, covering five language variants. The dictionary is the product of iterative expansion throughout Iteration 1, with each phrase manually verified for linguistic accuracy and clinical relevance.

Symptom Label | Phrase Count | Languages | Key Examples
HEADACHE | 38 | Tag/Bis/Eng | "masakit ang ulo", "labad akong ulo", "headache"
FEVER | 40 | Tag/Bis/Eng | "lagnat", "nilalagnat", "hilanat", "init akong lawas"
BODY_ACHES | 36 | Tag/Bis/Eng | "masakit katawan", "binugbog", "bug at akong lawas"
RASHES | 32 | Tag/Bis/Eng | "pantal", "rash", "makati ang balat"
STOMACH_ACHE | 30 | Tag/Bis/Eng | "sakit tiyan", "kabag", "hyperacidity"
SORE_THROAT | 28 | Tag/Bis/Eng | "masakit lalamunan", "sore throat", "garas"
COUGH_PRODUCTIVE | 20 | Tag/Bis/Eng | "may plema", "basang ubo", "halak"
ALLERGIC_RHINITIS | 17 | Tag/Bis/Eng | "allergy", "bahing", "alerdyi", "makati ilong"
COUGH_GENERAL | 16 | Tag/Bis/Eng | "ubo", "cough", "inuubo", "gi-ubo"
COUGH_DRY | 15 | Tag/Bis/Eng | "walang plema", "tuyong ubo", "dry cough"
DIARRHEA | 14 | Tag/Bis/Eng | "pagtatae", "diarrhea", "lbm", "loose bowel"
NASAL_CONGESTION | 11 | Tag/Bis/Eng | "barado ilong", "stuffy nose", "blocked nose"
RUNNY_NOSE | 10 | Tag/Bis/Eng | "sipon", "runny nose", "tumutulo ilong"

#### 3.5.2.1 Text Normalization

All input text undergoes deterministic normalization before phrase matching. The normalization pipeline includes: (1) conversion to lowercase, (2) leetspeak/Jejemon character substitution (@ → a, 0 → o, 1 → i, 3 → e, 4 → a, 5 → s, 7 → t, 8 → b, $ → s, ! → i, | → i), (3) removal of non-alphanumeric characters (preserving ñ for Filipino words), and (4) whitespace collapsing. This enables the system to handle informal digital communication styles common among Filipino youth (e.g., "s@k1t ul0" normalizes to "sakit ulo" and matches HEADACHE).

#### 3.5.2.2 Phrase Matching Strategy

The matching engine uses two strategies depending on phrase length: multi-word phrases use substring matching in the normalized text, while single-word keywords use word-boundary regular expressions (\b anchors) to prevent false positives from partial string matches (e.g., preventing "tubo" from matching the COUGH keyword "ubo").
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

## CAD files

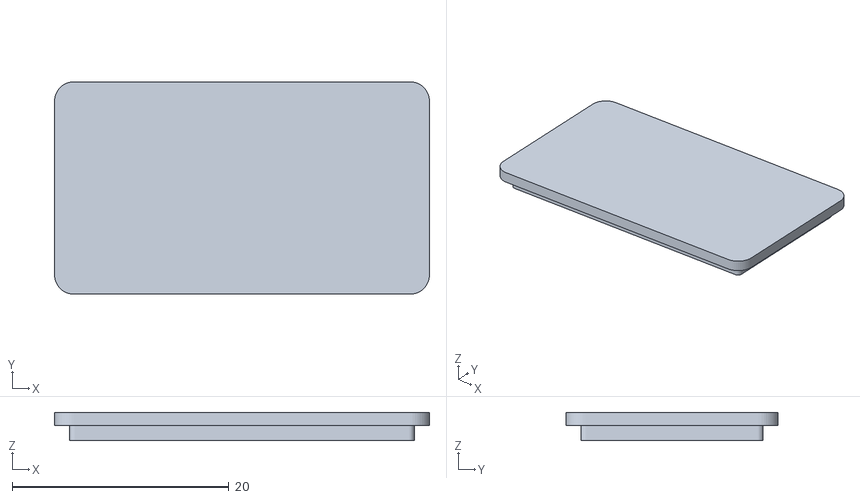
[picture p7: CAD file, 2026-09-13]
hardware/3d-print/PRINT-READY/MAIN - container lid loose.stl
34.6 x 19.6 x 2.60

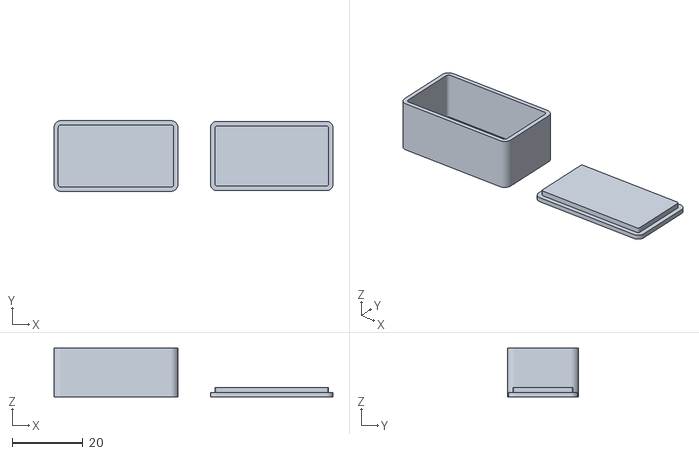
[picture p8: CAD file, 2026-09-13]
hardware/3d-print/PRINT-READY/MAIN - container body and lid.stl
78.8 x 20.0 x 13.8

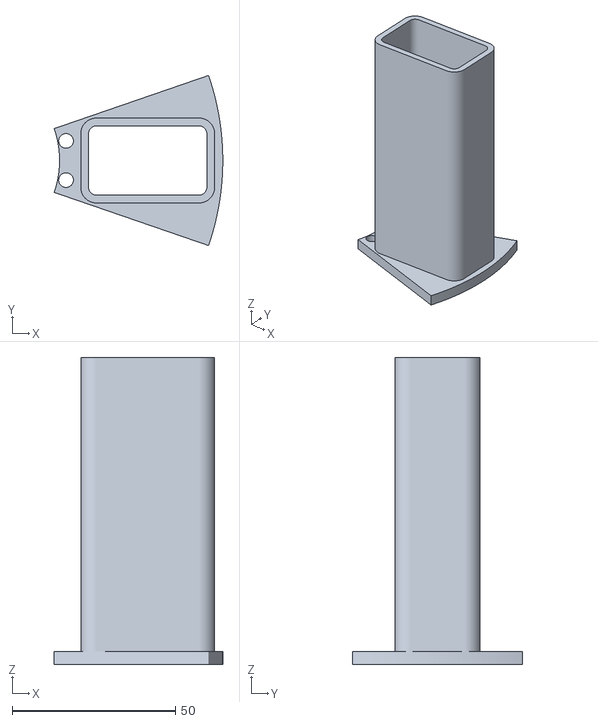
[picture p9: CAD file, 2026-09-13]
hardware/3d-print/PRINT-READY/MAIN - magazine tube 90mm.stl
51.6 x 52.1 x 94.0

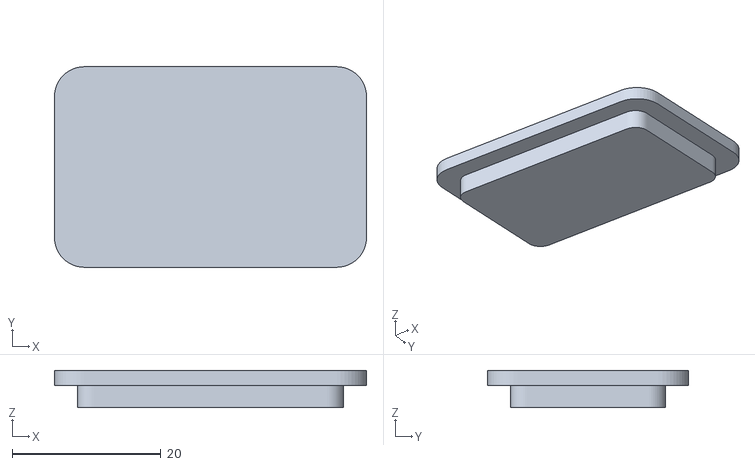
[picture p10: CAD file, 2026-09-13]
hardware/3d-print/PRINT-READY/MAIN - tube dust cap.stl
42.0 x 27.0 x 5.00

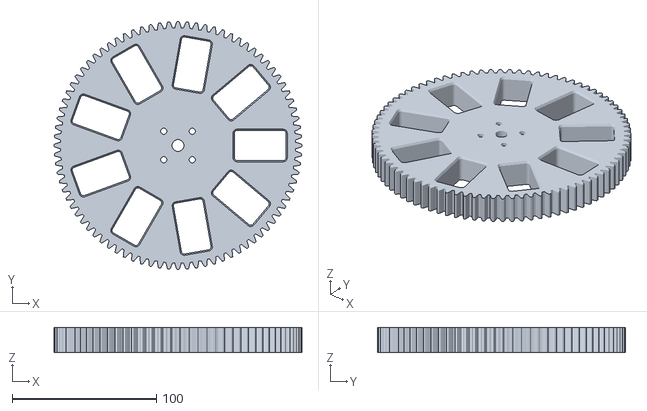
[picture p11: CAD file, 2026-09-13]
hardware/3d-print/PRINT-READY/MAIN - rotor 9 pocket.stl
172.0 x 172.0 x 17.5

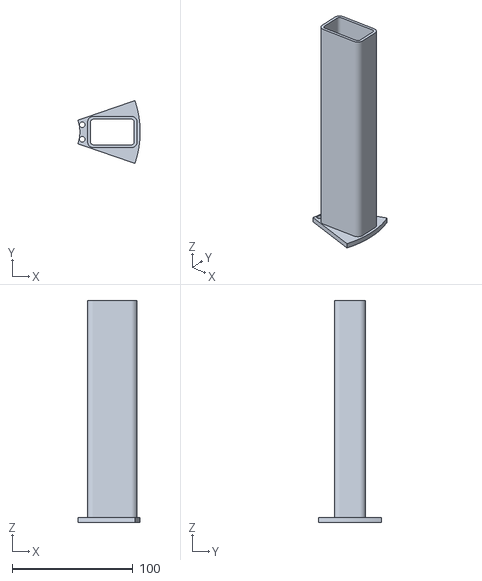
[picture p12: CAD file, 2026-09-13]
hardware/3d-print/PRINT-READY/MAIN - magazine tube 180mm.stl
51.6 x 52.1 x 184.0

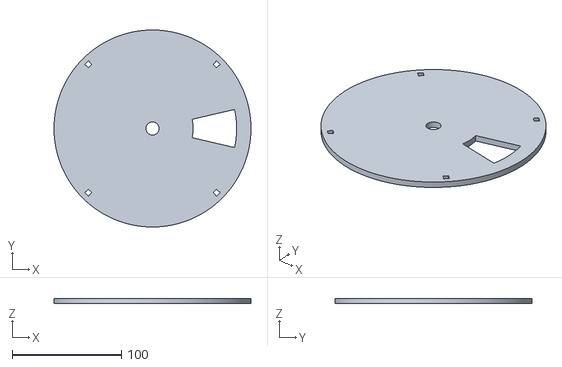
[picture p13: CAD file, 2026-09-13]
hardware/3d-print/PRINT-READY/MAIN - rotor deck plate.stl
180.0 x 180.0 x 5.00

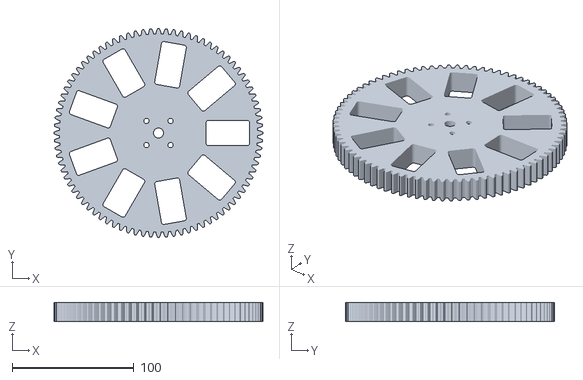
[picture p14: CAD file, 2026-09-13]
hardware/references/rotor_9pocket_35x20_recommended_clearance.stl
172.0 x 172.0 x 16.0

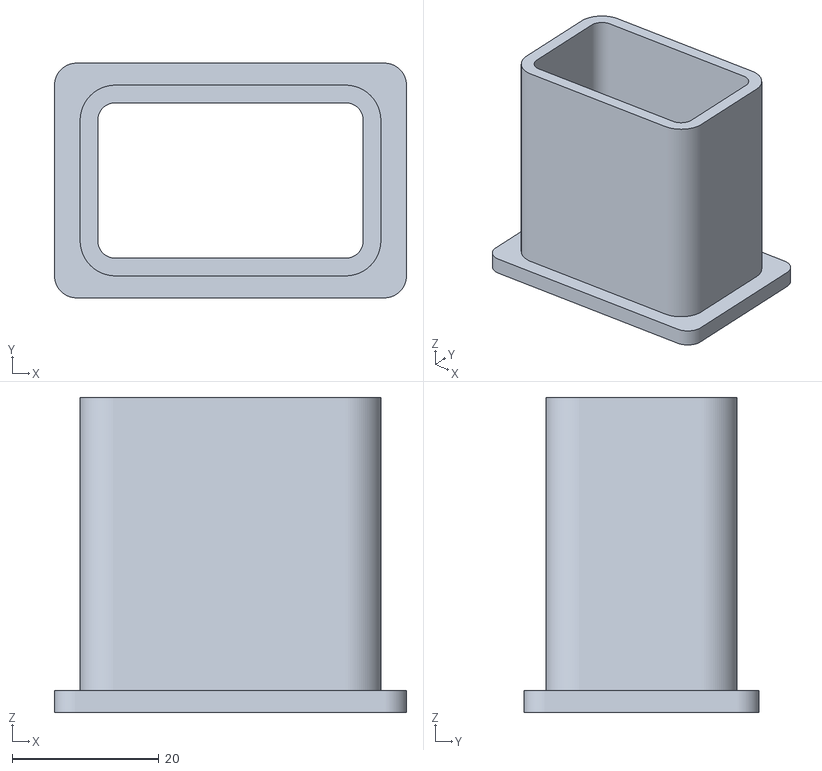
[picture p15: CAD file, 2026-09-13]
hardware/3d-print/PRINT-READY/PROTOTYPE - transfer tube 40mm.stl
48.0 x 32.0 x 43.0

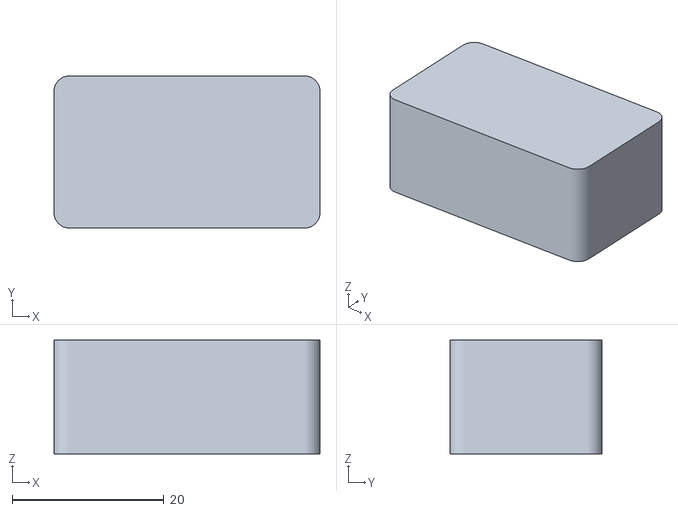
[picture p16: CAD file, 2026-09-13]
hardware/3d-print/PRINT-READY/PROTOTYPE - dummy container.stl
35.0 x 20.0 x 15.0

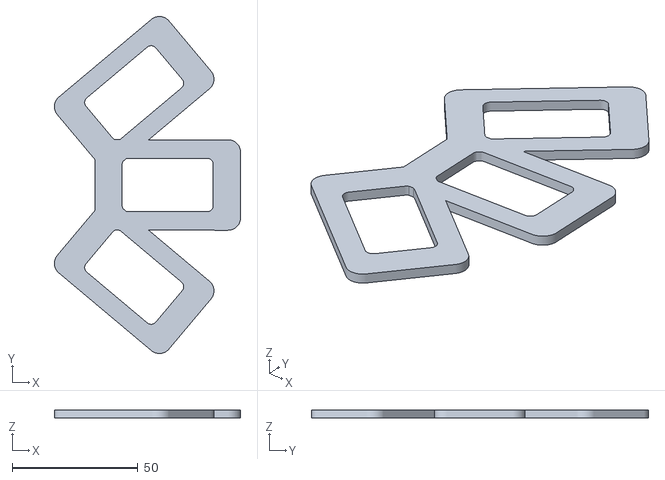
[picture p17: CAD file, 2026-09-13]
hardware/3d-print/PRINT-READY/PROTOTYPE - flange nesting coupon.stl
74.1 x 134.0 x 3.00

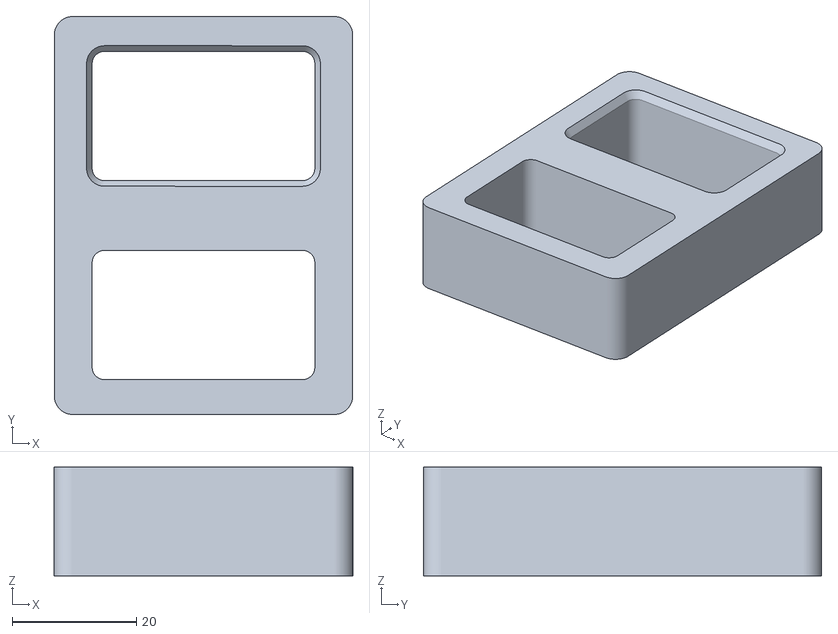
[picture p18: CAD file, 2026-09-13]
hardware/3d-print/PRINT-READY/PROTOTYPE - pocket coupon.stl
48.0 x 64.0 x 17.5

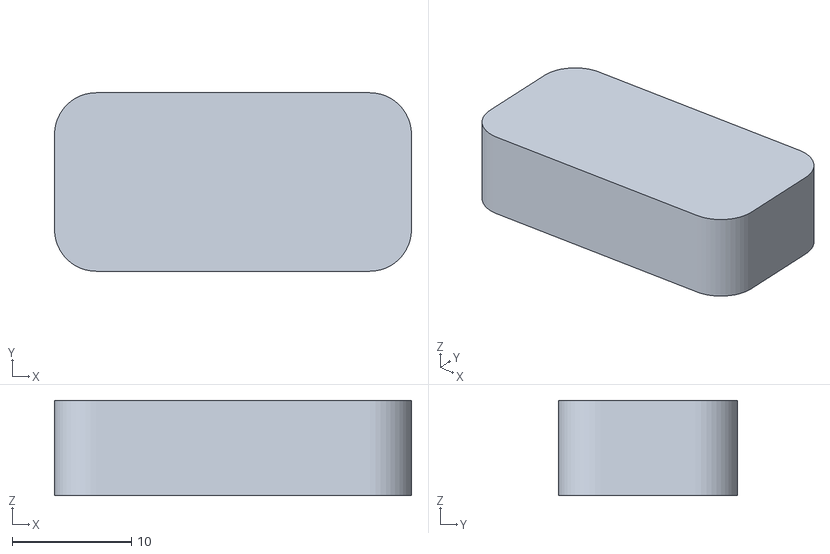
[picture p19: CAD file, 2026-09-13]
hardware/3d-print/PRINT-READY/PROTOTYPE - dummy blister.stl
30.0 x 15.0 x 8.00

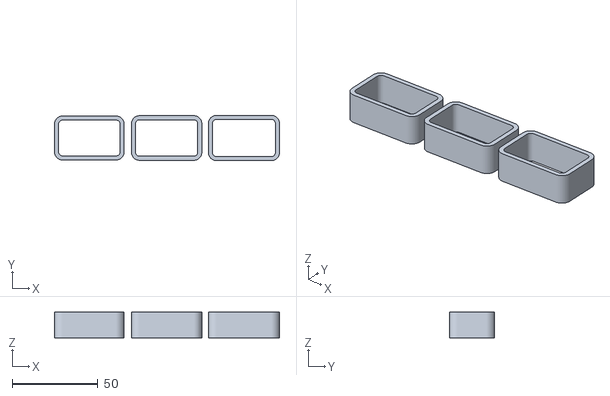
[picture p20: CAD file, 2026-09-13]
hardware/3d-print/PRINT-READY/PROTOTYPE - tube clearance gauge.stl
131.0 x 26.4 x 15.0

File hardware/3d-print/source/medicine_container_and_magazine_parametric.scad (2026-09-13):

// Parametric 35 x 20 mm POC medicine carrier and magazine tube
// Change `part` to export a specific component.
part = "container_body";
// Options: container_body, lid_normal, lid_loose, lid_tight,
// dummy_container, tube_180, tube_90, tube_cap, dummy_blister

$fn = 64;
container_l = 35.0;
container_w = 20.0;
container_h = 15.0;
body_h = 13.8;
wall = 1.2;
bottom = 1.2;
outer_r = 2.0;
lid_top_t = 1.2;
lid_plug_d = 1.4;
lid_top_l = 34.6;
lid_top_w = 19.6;

tube_in_l = 36.2;
tube_in_w = 21.2;
tube_in_r = 2.4;
tube_wall = 2.4;
tube_out_l = 41.0;
tube_out_w = 26.0;
tube_out_r = 4.8;
flange_l = 58.0;
flange_w = 42.0;
flange_t = 4.0;
flange_hole_d = 4.5;
flange_hole_dx = 46.0;
flange_hole_dy = 30.0;

module rr2d(l,w,r) {
    offset(r=r) square([l-2*r,w-2*r], center=true);
}

module container_body() {
    difference() {
        linear_extrude(body_h) rr2d(container_l,container_w,outer_r);
        translate([0,0,bottom])
            linear_extrude(body_h-bottom+0.2)
                rr2d(container_l-2*wall,container_w-2*wall,max(0.6,outer_r-wall));
    }
}

module lid(clearance=0.30) {
    cavity_l = container_l - 2*wall;
    cavity_w = container_w - 2*wall;
    union() {
        linear_extrude(lid_plug_d)
            rr2d(cavity_l-2*clearance,cavity_w-2*clearance,max(0.5,outer_r-wall-clearance));
        translate([0,0,lid_plug_d])
            linear_extrude(lid_top_t)
                rr2d(lid_top_l,lid_top_w,outer_r-0.2);
    }
}

module dummy_container() {
    linear_extrude(container_h) rr2d(container_l,container_w,outer_r);
}

module magazine_tube(h=180) {
    difference() {
        union() {
            linear_extrude(flange_t) rr2d(flange_l,flange_w,5);
            translate([0,0,flange_t])
                linear_extrude(h)
                    difference() {
                        rr2d(tube_out_l,tube_out_w,tube_out_r);
                        rr2d(tube_in_l,tube_in_w,tube_in_r);
                    }
        }
        translate([0,0,-0.1])
            linear_extrude(h+flange_t+0.2)
                rr2d(tube_in_l,tube_in_w,tube_in_r);
        for (x=[-flange_hole_dx/2,flange_hole_dx/2])
            for (y=[-flange_hole_dy/2,flange_hole_dy/2])
                translate([x,y,-0.1]) cylinder(d=flange_hole_d,h=flange_t+0.2);
    }
}

module tube_cap() {
    union() {
        linear_extrude(3.0)
            rr2d(tube_in_l-0.4,tube_in_w-0.4,2.1999999999999997);
        translate([0,0,3.0])
            linear_extrude(2.0) rr2d(42.0,27.0,4);
    }
}

module dummy_blister() {
    linear_extrude(8.0)
        rr2d(30.0,15.0,3.5);
}

if (part == "container_body") container_body();
else if (part == "lid_normal") lid(0.30);
else if (part == "lid_loose") lid(0.40);
else if (part == "lid_tight") lid(0.20);
else if (part == "dummy_container") dummy_container();
else if (part == "tube_180") magazine_tube(180);
else if (part == "tube_90") magazine_tube(90);
else if (part == "tube_cap") tube_cap();
else if (part == "dummy_blister") dummy_blister();

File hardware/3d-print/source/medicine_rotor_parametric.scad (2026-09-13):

// Medicine carrier rotor - editable OpenSCAD source
// Generated for a nominal 35 x 20 mm carrier.
// Recommended FDM pocket is 35.8 x 20.8 mm.

rotor_thickness = 16.000;
pocket_length = 35.800;
pocket_width = 20.800;
pocket_corner_radius = 2.000;
pocket_count = 9; // change to 1 for the safer one-pocket metering rotor
pocket_radius = 57.000;
center_bore_d = 8.200;
bolt_hole_d = 4.300;
bolt_circle_d = 28.000;

gear_outline = [
    [-41.597329, -74.252270],
    [-42.358027, -74.845157],
    [-42.679408, -74.662361],
    [-43.000000, -74.478185],
    [-43.319797, -74.292632],
    [-43.638794, -74.105706],
    [-43.505687, -73.150479],
    [-43.355986, -72.266094],
    [-43.193709, -71.452648],
    [-43.022865, -70.710063],
    [-42.847445, -70.038089],
    [-42.671418, -69.436302],
    [-42.487537, -69.542466],
    [-43.602306, -68.855566],
    [-44.227253, -68.448993],
    [-44.045512, -68.572902],
    [-44.511328, -68.992602],
    [-45.040644, -69.442208],
    [-45.635563, -69.918329],
    [-46.298043, -70.417477],
    [-47.029894, -70.936073],
    [-47.832771, -71.470455],
    [-48.139593, -71.264154],
    [-48.445525, -71.056535],
    [-48.750562, -70.847602],
    [-49.054697, -70.637360],
    [-48.850579, -69.694751],
    [-48.635206, -68.824026],
    [-48.412594, -68.024982],
    [-48.186734, -67.297241],
    [-47.961588, -66.640255],
    [-47.741082, -66.053305],
    [-47.556447, -66.179187],
    [-48.549493, -65.461414],
    [-49.227083, -64.945871],
    [-49.046811, -65.089633],
    [-49.542689, -65.473349],
    [-50.104124, -65.882142],
    [-50.732960, -66.312473],
    [-51.430889, -66.760718],
    [-52.199448, -67.223173],
    [-53.040015, -67.696062],
    [-53.330562, -67.467408],
    [-53.620123, -67.237507],
    [-53.908693, -67.006364],
    [-54.196267, -66.773982],
    [-53.922278, -65.849262],
    [-53.642438, -64.997067],
    [-53.360736, -64.216892],
    [-53.081123, -63.508065],
    [-52.807510, -62.869741],
    [-52.543758, -62.300911],
    [-52.362877, -62.445159],
    [-53.233587, -61.712521],
    [-53.946460, -61.082170],
    [-53.773821, -61.242356],
    [-54.296987, -61.587942],
    [-54.887401, -61.953637],
    [-55.546638, -62.335771],
    [-56.276113, -62.730607],
    [-57.077082, -63.134334],
    [-57.950637, -63.543085],
    [-58.223284, -63.293358],
    [-58.494855, -63.042461],
    [-58.765345, -62.790399],
    [-59.034749, -62.537176],
    [-58.692422, -61.635518],
    [-58.349680, -60.806618],
    [-58.010463, -60.049676],
    [-57.678661, -59.363726],
    [-57.358111, -58.747634],
    [-57.052587, -58.200105],
    [-56.879917, -58.360320],
    [-57.629203, -57.629203],
    [-58.360320, -56.879917],
    [-58.200105, -57.052587],
    [-58.747634, -57.358111],
    [-59.363726, -57.678661],
    [-60.049676, -58.010463],
    [-60.806618, -58.349680],
    [-61.635518, -58.692422],
    [-62.537176, -59.034749],
    [-62.790399, -58.765345],
    [-63.042461, -58.494855],
    [-63.293358, -58.223284],
    [-63.543085, -57.950637],
    [-63.134334, -57.077082],
    [-62.730607, -56.276113],
    [-62.335771, -55.546638],
    [-61.953637, -54.887401],
    [-61.587942, -54.296987],
    [-61.242356, -53.773821],
    [-61.082170, -53.946460],
    [-61.712521, -53.233587],
    [-62.445159, -52.362877],
    [-62.300911, -52.543758],
    [-62.869741, -52.807510],
    [-63.508065, -53.081123],
    [-64.216892, -53.360736],
    [-64.997067, -53.642438],
    [-65.849262, -53.922278],
    [-66.773982, -54.196267],
    [-67.006364, -53.908693],
    [-67.237507, -53.620123],
    [-67.467408, -53.330562],
    [-67.696062, -53.040015],
    [-67.223173, -52.199448],
    [-66.760718, -51.430889],
    [-66.312473, -50.732960],
    [-65.882142, -50.104124],
    [-65.473349, -49.542689],
    [-65.089633, -49.046811],
    [-64.945871, -49.227083],
    [-65.461414, -48.549493],
    [-66.179187, -47.556447],
    [-66.053305, -47.741082],
    [-66.640255, -47.961588],
    [-67.297241, -48.186734],
    [-68.024982, -48.412594],
    [-68.824026, -48.635206],
    [-69.694751, -48.850579],
    [-70.637360, -49.054697],
    [-70.847602, -48.750562],
    [-71.056535, -48.445525],
    [-71.264154, -48.139593],
    [-71.470455, -47.832771],
    [-70.936073, -47.029894],
    [-70.417477, -46.298043],
    [-69.918329, -45.635563],
    [-69.442208, -45.040644],
    [-68.992602, -44.511328],
    [-68.572902, -44.045512],
    [-68.448993, -44.227253],
    [-68.855566, -43.602306],
    [-69.542466, -42.487537],
    [-69.436302, -42.671418],
    [-70.038089, -42.847445],
    [-70.710063, -43.022865],
    [-71.452648, -43.193709],
    [-72.266094, -43.355986],
    [-73.150479, -43.505687],
    [-74.105706, -43.638794],
    [-74.292632, -43.319797],
    [-74.478185, -43.000000],
    [-74.662361, -42.679408],
    [-74.845157, -42.358027],
    [-74.252270, -41.597329],
    [-73.680433, -40.906280],
    [-73.133173, -40.282954],
    [-72.613925, -39.725278],
    [-72.126020, -39.231042],
    [-71.672683, -38.797893],
    [-71.571337, -38.973430],
    [-71.876583, -38.418834],
    [-72.517035, -37.184430],
    [-72.430983, -37.363119],
    [-73.044242, -37.493682],
    [-73.727446, -37.618394],
    [-74.480722, -37.733268],
    [-75.304020, -37.834302],
    [-76.197120, -37.917495],
    [-77.159623, -37.978844],
    [-77.322187, -37.646771],
    [-77.483323, -37.314002],
    [-77.643026, -36.980543],
    [-77.801294, -36.646400],
    [-77.153218, -35.932136],
    [-76.531337, -35.285752],
    [-75.939027, -34.705065],
    [-75.379556, -34.187753],
    [-74.856081, -33.731359],
    [-74.371642, -33.333299],
    [-74.294603, -33.493273],
    [-74.508095, -33.027167],
    [-75.087018, -31.676643],
    [-75.020601, -31.845870],
    [-75.641902, -31.930239],
    [-76.332515, -32.003547],
    [-77.092269, -32.061807],
    [-77.920816, -32.101033],
    [-78.817635, -32.117252],
    [-79.782031, -32.106502],
    [-79.919325, -31.763209],
    [-80.055142, -31.419328],
    [-80.189480, -31.074867],
    [-80.322335, -30.729831],
    [-79.622694, -30.065995],
    [-78.954248, -29.467892],
    [-78.320199, -28.933092],
    [-77.723633, -28.459036],
    [-77.167516, -28.043038],
    [-76.654684, -27.682293],
    [-76.602428, -27.815440],
    [-76.735841, -27.456523],
    [-77.238717, -25.994772],
    [-77.190673, -26.150526],
    [-77.816541, -26.188229],
    [-78.510702, -26.209722],
    [-79.272685, -26.211043],
    [-80.101847, -26.188242],
    [-80.997370, -26.137396],
    [-81.958267, -26.054607],
    [-82.069522, -25.702014],
    [-82.179261, -25.348945],
    [-82.287481, -24.995408],
    [-82.394180, -24.641409],
    [-81.646887, -24.031713],
    [-80.935614, -23.485236],
    [-80.263372, -22.999314],
    [-79.633049, -22.571164],
    [-79.047398, -22.197888],
    [-78.509043, -21.876476],
    [-78.480398, -21.969340],
    [-78.547749, -21.737090],
    [-78.960700, -20.170329],
    [-78.929063, -20.308937],
    [-79.555999, -20.299764],
    [-80.249825, -20.269323],
    [-81.009776, -20.213696],
    [-81.834916, -20.128996],
    [-82.724135, -20.011370],
    [-83.676158, -19.857004],
    [-83.760753, -19.497082],
    [-83.843800, -19.136800],
    [-83.925298, -18.776165],
    [-84.005244, -18.415182],
    [-83.214478, -17.863036],
    [-82.464355, -17.371240],
    [-81.757681, -16.936914],
    [-81.097124, -16.557066],
    [-80.485216, -16.228599],
    [-79.924347, -15.948317],
    [-79.916007, -15.984857],
    [-79.934000, -15.899861],
    [-80.243866, -14.235576],
    [-80.226051, -14.353773],
    [-80.850548, -14.297775],
    [-81.540159, -14.215569],
    [-82.293828, -14.103306],
    [-83.110330, -13.957181],
    [-83.988273, -13.773431],
    [-84.926098, -13.548353],
    [-84.983560, -13.183116],
    [-85.039451, -12.817635],
    [-85.093770, -12.451917],
    [-85.146517, -12.085969],
    [-84.316700, -11.594462],
    [-83.531923, -11.160098],
    [-82.794767, -10.779796],
    [-82.107671, -10.450373],
    [-81.472928, -10.168553],
    [-80.892681, -9.930968],
    [-80.890588, -9.944855],
    [-81.081499, -8.223351],
    [-81.074381, -8.318337],
    [-81.692947, -8.215826],
    [-82.374487, -8.082315],
    [-83.117659, -7.914045],
    [-83.920958, -7.707311],
    [-84.782715, -7.458467],
    [-85.701097, -7.163934],
    [-85.731104, -6.795424],
    [-85.759527, -6.426788],
    [-85.786364, -6.058034],
    [-85.811616, -5.689167],
    [-84.947389, -5.261046],
    [-84.132346, -4.886543],
    [-83.368831, -4.562392],
    [-82.659038, -4.285238],
    [-82.005010, -4.051640],
    [-81.408631, -3.858082],
    [-81.405464, -3.900342],
    [-81.469311, -2.166892],
    [-81.469311, -2.236381],
    [-82.078487, -2.087931],
    [-82.748143, -1.903862],
    [-83.476663, -1.680526],
    [-84.262266, -1.414339],
    [-85.103017, -1.101791],
    [-85.996821, -0.739451],
    [-85.999205, -0.369729],
    [-86.000000, 0.000000],
    [-85.999205, 0.369729],
    [-85.996821, 0.739451],
    [-85.103017, 1.101791],
    [-84.262266, 1.414339],
    [-83.476663, 1.680526],
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

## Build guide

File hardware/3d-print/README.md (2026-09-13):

# 3D print queue — rotor / tube / container POC

Print-ready STLs for the magazine/container dispensing mechanism, staged so the
cheap gauges validate the critical fit **before** you commit filament to tubes
and containers you would have to reprint.

Source package: `~/Downloads/medicine_vendo_rotor_tube_container_POC_package/`.
All numbers below were measured from the meshes themselves, not copied from the
supplied README. Mesh QA: all 14 STLs watertight, single-body, zero degenerate
faces, euler numbers matching expected hole counts.

## Target architecture — SUPERSEDED, see `MECHANISM.md`

> **This section was written against a design that is no longer being built.**
> The mechanism is now **one 9-pocket rotor per medicine, ten rotors, one motor
> each**, with a single stationary tube and a single drop hole in a deck plate.
> Read [`MECHANISM.md`](MECHANISM.md) — it is the authority.
>
> What changed and why it matters:
>
> | Old text | Now |
> | --- | --- |
> | "the 9-pocket rotor does not belong to this build" | it *is* the build — one per medicine |
> | rotor = shared 9-medicine carousel | rotor = **9 doses of one** medicine |
> | 10 rotors need 860 × 344 mm of deck | accepted; cabinet sized for it |
> | SG90-class servo | **MG90S minimum** — see the servo table below |
>
> The rotor is not indexed by a servo sweep directly. It is advanced by a
> **9-tooth ratchet**, one tooth per pocket, driven by the existing
> A → B → A `DISPENSE_ONE` motion. That keeps `motion_profiles` valid 1:1 and
> sidesteps the 84/9 = 9.333 problem below.

Retained because the tolerance, fit and print-settings analysis below is
architecture-independent and still correct.

`hardware/README.md` locks `PCA channels 0–9 → hardware slots 1–10`, and
`pos/db.py` seeds `motion_profiles` with `position_a_us` / `position_b_us` /
`travel_time_ms` / `b_dwell_ms` / `return_settle_ms` — one sweep-and-return per
slot. That mapping is unchanged: ten slots, ten medicines, ten rotors.

The container / tube / pocket **fit interface is identical either way**, so the
fit gauges below are valid and worth printing now.

---

## Nominal interface

| Feature | Size |
| --- | --- |
| Container (closed) | 35.0 × 20.0 × 15.0 mm |
| Container cavity | 32.6 × 17.6 × 11.2 mm |
| Rotor pocket | 35.8 × 20.8 mm, 9 off @ 40.000° |
| Rotor | OD 172, 16 mm thick, 84T module-2 gear, 8.2 bore, 4× M4 @ 28 PCD |
| Magazine bore | 36.2 × 21.2 mm |
| Pocket centre radius | 57.0 mm |

Measured clearances (from section polygons, corners included):

| Fit | Flats | True min (incl. corners) | Lateral float | Yaw float |
| --- | --- | --- | --- | --- |
| container → magazine bore | 0.600 mm | 0.600 mm | ±0.600 mm | ±2.25° |
| container → rotor pocket | 0.400 mm | 0.400 mm | ±0.400 mm | ±1.49° |

---

## Stage 1 — fit gauges (print first, ~1 h)

| File | Qty | Notes |
| --- | --- | --- |
| `rotor_1pocket_35x20_recommended_clearance.stl` | 1 | identical pocket, 1/9 the print time |
| `container_dummy_solid_35x20x15.stl` | **3** | need ≥3 to test stacking |
| `tube_clearance_gauge_35x20.stl` | 1 | |
| `fit_gauge_35x20_clearance_test.stl` | 1 | |

### Pass/fail gate

1. Dummy falls through the tube gauge **under its own weight**, no shaking.
2. Dummy enters the rotor pocket with **no force**.
3. **The one that matters:** push the dummy hard against one side and yaw it
   ~2°, then try to drop it in. Centred and square it will *always* work — that
   is what will mislead you. The tube allows ±0.600 mm / ±2.25°; the pocket only
   accepts ±0.400 mm / ±1.49°, so the tube can present positions the pocket
   rejects. If it hangs on the lip here, chamfer the pocket before going on.

Do not proceed to stage 2 until all three pass.

---

## Stage 2 — functional parts (only after stage 1 passes)

| File | Qty | Notes |
| --- | --- | --- |
| `magazine_tube_90mm_ID36p2x21p2.stl` | 1 | short tube first, never the 180 mm |
| `medicine_container_body_35x20x15.stl` | 2–3 | |
| `medicine_container_lid_loose.stl` | 2–3 | **start with LOOSE** — see tolerances |
| `medicine_container_lid_normal.stl` | 1 | only if LOOSE is too easy to remove |
| `magazine_tube_dust_cap.stl` | 1 | 0.20 mm/side plug — may need scaling |
| `dummy_blister_30x15x8.stl` | 2–3 | 1.3 mm/side, 3.2 mm headroom in cavity |

The supplied README says start with NORMAL. **That is wrong for most printers** —
see the tolerance table below.

---

## Per-slot mechanism — decide before designing anything new

Two viable ways to build one slot with one 9 g servo:

| | Metering disc | **Pusher paddle (recommended)** |
| --- | --- | --- |
| Principle | pocket rotates from under tube to over drop hole | paddle shoves bottom container out from under the stack |
| Size per slot | 87–96 mm disc | ~60 × 60 mm |
| 10 slots | ~500 × 200 mm | **~300 × 120 mm** |
| Servo sweep | >73–91° (SG90's 180° is enough) | 90° on a 30 mm horn = 42 mm stroke |
| Printing | 10 discs | 10 small paddles |
| Fits `motion_profiles`? | yes | yes, 1:1 |

Minimum disc sizes, pocket long-side turned tangential:

| Pocket radius | Disc OD | Sweep needed |
| --- | --- | --- |
| R = 25 mm | 87 mm | >91° |
| R = 30 mm | 96 mm | >73° |
| R = 57 mm (as drawn) | 148 mm | >37° |

Ejection stroke for a 35 mm container is ~38–40 mm, so a pusher horn must be
≥30 mm (a 25 mm horn at 90° gives only 35.4 mm — too short).

### Servo choice

Torque is **not** the constraint: shearing one container out from under a
12-high stack needs ~10 mN·m, and even an SG90 delivers ~177 mN·m.

| Servo | Torque | Gears |
| --- | --- | --- |
| SG90 (9 g) | 1.8 kg·cm = 177 mN·m | **plastic — strips on stall** |
| MG90S (13.4 g) | 2.2 kg·cm = 216 mN·m | metal, same 23 × 12 body |
| MG996R (55 g) | 10 kg·cm = 981 mN·m | metal — what `hardware/README.md` specifies |

**Use MG90S at minimum.** An SG90 stalls destructively and the first jam strips
it; with 10 units that is a recurring failure. Keep the firmware's "only one
servo active at a time" rule — 10 stalled servos would draw ~7 A.

---

## Print settings

Material PETG preferred (PLA/PLA+ fine for dry indoor fit tests), 0.4 mm nozzle.

| Part | Layer | Walls | Infill | Orientation |
| --- | --- | --- | --- | --- |
| container body | 0.20 | 3–4 | 20–30 % | open side **up** |
| lid | 0.20 | 3–4 | 20–30 % | large flat top on bed, plug **up** |
| tube | 0.24–0.28 | 4 | 15–25 % | upright on flange, 8–12 mm brim |
| tube cap | 0.20 | 3–4 | 20–30 % | flat top on bed, plug **up** |
| rotor | 0.20–0.24 | 4 | 25–30 % | flat, brim (rim warping risk) |

**No supports on any part** — verified, zero downward-facing area below 45°.

**Enable elephant-foot compensation (0.15–0.25 mm).** This is not optional here:
the container prints open-side-up, so its 35 × 20 bottom face — the exact face
that must clear the pocket — sits on the bed.

```
elephant's foot  →  resulting pocket gap per side
    +0.10 mm            0.300 mm   ok
    +0.20 mm            0.200 mm   marginal
    +0.30 mm            0.100 mm   BINDS
```

Alternative if your printer can't compensate: chamfer the container's bottom
edge 0.5 mm.

### Lid clearance vs real FDM tolerance

Holes print 0.10–0.20 mm undersize per side, walls 0.05–0.15 mm oversize:

| Lid | Nominal | Good printer | Typical printer |
| --- | --- | --- | --- |
| TIGHT (0.20) | 0.200 | −0.05 press-fit | **−0.25 won't assemble** |
| NORMAL (0.30) | 0.300 | +0.05 press-fit | **−0.15 won't assemble** |
| LOOSE (0.40) | 0.400 | +0.15 free | −0.05 press-fit |

Same issue on the tube dust cap (0.20 mm/side).

---

## Open design issues

### 1. Nine tube flanges do not fit around the rotor — VOID for this build (see 5)

At R = 57 mm, adjacent pocket centres are **38.99 mm** apart. The tube flange is
**42 mm** across that direction.

```
9 flanges × 42 mm  = 378 mm needed
circumference @R57 = 358 mm available
→ each flange overlaps its neighbour by 3.01 mm
```

Tube *bodies* (26 mm) clear fine — it is purely the 58 × 42 mm bolt flange.
Options: replace per-tube flanges with one 9-hole carousel deck (cleanest); trim
the flange to ≤ 37 mm tangential; or move pockets to R ≥ 64.3 mm (grows the
rotor, forces gear regeneration).

### 2. Magazine bore is larger than the rotor pocket — inverted

The exit aperture must be larger than the guide aperture; here it is backwards
by 0.2 mm per side. A container resting against one tube wall overhangs the
pocket lip; one yawed 1.5–2.25° cannot enter at all. The pocket top edge is a
sharp extruded 90° with no lead-in.

**Fix: chamfer the pocket top edge ~1.5 mm × 45°.** That opens the capture mouth
to 38.8 × 23.8 mm — swallows anything the tube can present — while the pocket
stays 35.8 × 20.8 lower down to limit cocking.

### 3. A cocked container stands proud of a 16 mm pocket — STILL APPLIES

```
pocket ALLOWS a 3.28° cock → container stands 16.98 mm tall
rotor thickness             16.00 mm
```

A guide plate at 16.2–16.5 mm still shears anything cocked past 1.98–2.48°, so
there is a live window (~2°–3.3°) where a container is legally in the pocket,
standing proud, and gets sheared by the fixed top plate.

**Fix: rotor thickness ≥ 17.3 mm**, plus the chamfer from issue 2.

### 4. Lid retention

Friction plug only, no latch — the supplied README tells you to tape the seam.
Across a 90–180 mm stack drop plus tumbling out the chute, lids will pop and
spill blisters into the mechanism. Needs a snap bead before this is more than a
bench demo.

### 5. Issue 1 is void — but for a different reason than written here

Issue 1 (nine tube flanges colliding at R=57) is dead because there is now
**one stationary tube per rotor**, not nine rotating ones. Nothing tiles, so
nothing collides. The flange shape is irrelevant; bolt the tube to a frame.

The indexing problem is **not** void. 84/9 = 9.333 still means this rotor cannot
be indexed by tooth counting — which is why `MECHANISM.md` specifies a 9-tooth
ratchet instead, one tooth per pocket, integer by construction.

**Issue 3 still applies in modified form:** whatever pocket or paddle the
container passes through must give it ≥1 mm of vertical headroom, because a
container cocked 3.28° stands 16.98 mm tall against a 15.0 mm nominal.

Retained for reference only, in case the shared carousel is ever revisited:
`84 / 9 = 9.333` teeth per index is not an integer, so that design could never
be indexed by tooth-counting or a Geneva — it would need an absolute homing
datum every cycle, plus a bearing (67–118 mN·m of sliding drag if a 172 mm disc
runs flat on a plate, vs ~16 mN·m of inertia).

---

## Safety

Use the dummy blister or an empty sealed sample for all mechanism tests. Do not
put loose tablets or capsules in the printed carrier — these parts are not
validated pharmaceutical-contact packaging. Sealed blisters stay intact.

---

## Directory layout

```
3d-print/
├── MECHANISM.md             ** the authority on how the machine works **
├── PRINT-READY/             MAIN - (real parts) and PROTOTYPE - (test coupons)
├── stage1-fit-gauges/       validates the critical fit
├── stage2-functional/       earlier functional revision
├── fixed-v2/                corrected rotor + wedge-flange tubes
├── superseded/              defective originals, kept for provenance
├── source/                  editable OpenSCAD, + deck_plate_generator.py
└── previews/                assembly reference renders
```

`source/medicine_rotor_parametric.scad` — edit `rotor_thickness`,
`pocket_radius`, `pocket_count` there; the gear outline is a baked point list,
so changing the OD requires regenerating it, not just editing a variable.

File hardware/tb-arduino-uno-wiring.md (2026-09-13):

# TB bill acceptor to Arduino Uno wiring

See the companion [editable wiring diagram](tb-arduino-uno-wiring.svg).

This is a **bench/reference schematic**, not physical acceptance evidence. It
uses the supplied TOPVME WEL-R7U02 harness mapping and the TB manual's isolated
customer-side interfaces. The exact connected TB model, PHP firmware label,
DIP sheet, and inhibit polarity are still pending.

## Connections shown

| TB harness | Connect to | Notes |
| --- | --- | --- |
| Pin 5, red, `+12 V DC` | Fused regulated 12 V positive | TB power domain only |
| Pin 9, orange, `12 V GND` | 12 V supply return | Do not route this to an Uno input |
| Pin 7, blue, `METER+` | Arduino D3 / INT1 and the R1 node | Isolated open-collector pulse output |
| Pin 8, purple, `METER-` | Arduino logic GND | Customer-side meter return |
| Pin 1, yellow, `INHIBIT+` | R2 1 kΩ, then Arduino 5 V logic | Verify polarity on the exact unit |
| Pin 2, green, `INHIBIT-` | Q1 NPN collector | Q1 emitter returns to Arduino logic GND |

The METER node gets an external **R1 = 4.7 kΩ pull-up to Arduino 5 V**. The
Arduino counts the conditioned pulse signal on D3; firmware must use the
measured source-specific pulse gap and calibrated pulse-count mapping.

The inhibit driver uses the manual's NPN open-collector arrangement. The
diagram shows **R3 = 2.2 kΩ** from D4 to the transistor base and **R4 = 100
kΩ** as a base pulldown. These are interface-design starting values, not
bench-validated values. Confirm base current, transistor ratings, the TB DIP
polarity, and the required inactive level before enabling cash.

## Common wiring mistakes

1. **Putting the pull-up in series.** R1 is a *pull-up*: it goes between the
   Arduino 5 V pin and the METER+ signal node. It does not go in line between
   METER+ and the Arduino input. The TB credit output is an opto-isolated open
   collector — it can only pull down, so without a pull-up the pin has no
   defined idle level.
2. **Bonding pin 9 (orange, 12 V GND) to Arduino ground.** This defeats the
   optocoupler, which is the entire reason it is fitted. Motor current up to
   1.2 A then shares a return path with your logic reference and injects noise
   directly into the signal. Pin 9 belongs to the 12 V supply return only.
   Pin 8 (purple, METER-) is the customer-side emitter and *is* the conductor
   that goes to Arduino logic ground.
3. **Landing a ground conductor on an input pin.** A pin the internal pull-up
   cannot lift is tied to ground; an idle METER+ must read HIGH. Use
   `hardware/firmware/line_check` to check this before trusting any counts.

Only two conductors touch the Arduino: **blue (pin 7) to D3**, and **purple
(pin 8) to Arduino GND**. Red and orange go to the fused 12 V supply and
nowhere else.

Optional noise filter: 100 nF from the signal node to Arduino GND. With
R1 = 4.7 kΩ that is a ~470 µs time constant, roughly 100x faster than the
50 ms credit pulse, so it removes microsecond glitches without distorting the
signal. Use 1 µF only if noise persists.

## Do not power until all are true

1. Continuity identifies every WEL-R7U02 conductor and the exact TB model.
2. The exact Philippine currency/DIP sheet for that TB unit is available; do
   not substitute a TP-series sheet.
3. Reset, USB loss, daemon failure, and missing heartbeat produce **bill
   inhibited** at the physical unit.
4. The 12 V rail is isolated from the Uno, and every conditioned Uno-side
   signal measures 0–5 V in all expected states.
5. The 12 V supply is fused/current-limited, with a master disconnect. The
   Arduino is powered from USB; no acceptor load is powered from an Uno pin.

The enabled denominations remain ₱20, ₱50, and ₱100. Higher denominations are
not enabled by this drawing. Record twenty correct trials per enabled
denomination and rejection trials for ₱200/₱500/₱1000 before clearing the
physical Phase-0 gate.

Source: the supplied TB installation guide, printed page 13 (PDF page 16) for
the pulse/inhibit interfaces and printed page 10 for the WEL-R7U02 harness.

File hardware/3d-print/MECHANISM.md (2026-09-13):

# Dispensing mechanism — one rotor per medicine

**Architecture confirmed 2026-08-04: ten rotors, ten OTC medicines, one motor
each. Every pocket in a given rotor holds the same medicine.**

This is the authority for the mechanism. Where `README.md` or
`PRINT-READY/PRINT-THIS.md` disagree, this file wins.

## The mechanism

Two **stations** are fixed in space. The rotor indexes underneath them.

```
                 TUBE (reload)
                      |
                      v
              . . .  [12]  [1]  . . .
                            ^
                            |
                      HOLE (dispense)
                    aperture in the deck

     rotor turns COUNTER-CLOCKWISE, one pocket per index
     a pocket travels:  [2] -> [1] -> [12] -> ...
```

One index step, in order:

1. The loaded pocket arriving at **[1]** sits over the deck aperture. Its
   container **falls through** — the dispense.
2. The pocket that just emptied arrives at **[12]**, under the tube. One
   container **drops in** from the stack — the reload.

Nine pockets, nine doses per revolution. The rotor is full at rest except for
the pocket crossing the hole.

The clock is an analogy only. Nine pockets index at **360 / 9 = 40.000°**, not
the 30° of a clock hour. Never lay anything out from clock positions.

## Why a single stationary tube is the right choice

The abandoned design bolted a magazine above every pocket, turning with the
rotor. It could not meter, and `PRINT-THIS.md` said so:

> the pocket is 16 mm and the container 15 mm, so the tube stacks straight onto
> the pocket and only a 0.8 mm timing window separates one container from the
> whole column

That is unavoidable when the tube rides over its own pocket — nothing ever comes
between the stack and the hole.

**A stationary tube makes the rotor its own shutter.**

| Rotor position | The stack rests on | Result |
| --- | --- | --- |
| pocket aligned under tube | the empty pocket | one container drops in |
| pocket moved away | solid rotor between pockets | column held up |

### The numbers that make it work

| Quantity | Value | Source |
| --- | --- | --- |
| Pocket pitch at R57 | 2π(57)/9 = **39.8 mm** | geometry |
| Pocket tangential width | **20.8 mm** | `medicine_rotor_parametric.scad` |
| Land between pockets | 39.8 − 20.8 = **19.0 mm** | |
| Container tangential width | **20.0 mm** | container spec |
| Rotor thickness | **17.5 mm** | vs 15.0 mm container |

A seated container sits entirely below the top face (15.0 in 17.5), so the next
one in the stack has flat material to rest on.

**Known limitation.** The tube bore is 21.2 mm tangential but the land is only
19.0 mm, so the bore is never *fully* covered — about 2.2 mm always overlaps a
pocket. This does not leak, because a 20.0 mm container cannot pass a 2.2 mm
slot. But it does mean the container only begins to enter in the last ~0.8 mm of
alignment. **Dwell at the reload station until the drop completes** — a 15 mm
fall is ~55 ms free, so allow 200–300 ms for friction. `motion_profiles`
already carries `b_dwell_ms` and `return_settle_ms` for exactly this.

## Parts

### The deck plate — was missing, now generated

`medicine_rotor_parametric.scad` cuts the pockets **through**:

```scad
translate([0, 0, -0.5])
linear_extrude(height = rotor_thickness + 1.0)   // through-cut
```

So nothing held a container up. The deck is the floor the loaded rotor slides
on, and it carries the single drop aperture.

`PRINT-READY/MAIN - rotor deck plate.stl`, generated by
`source/deck_plate_generator.py` (edit constants, re-run, reprint):

| Feature | Value | Why |
| --- | --- | --- |
| OD | 180 mm | 4 mm of rim support beyond the 172 mm rotor |
| Thickness | 5 mm | stiffness under nine loaded pockets |
| Centre bore | 12 mm | drive shaft / hub clearance |
| Drop aperture | 39.8 mm radial × 26.0 mm tangential at R57 | pocket is 35.8 × 20.8 — **2 mm and 2.6 mm of clearance per side** |
| Mounting | 4× M4 clearance @ R83 | clear of the pocket circle and the aperture |

The aperture is deliberately the loose feature. The pocket allows ±1.49° of yaw
and a cocked container stands 16.98 mm; the exit must never be what catches it.

Mesh verified watertight: 4580 triangles, **0 non-manifold edges**, outward
normals, Euler −10 (genus 6 = centre bore + aperture + 4 bolts). ~121 cm³,
**~69 g PETG**.

### No longer needed

| Part | Why |
| --- | --- |
| 8 of the 9 magazine tubes | one stationary tube serves every pocket |
| `PROTOTYPE - flange nesting coupon` | proves nine wedge flanges tile 342°. One tube, nothing to tile. |
| the 40° wedge flange geometry | packed nine flanges around R57. A stationary tube bolts to a frame with any bracket. |

This voids **open issue 1** in `README.md` (nine flanges overlapping by 3.01 mm)
— an artefact of the nine-tube design that no longer exists.

The existing tube STL is still usable as printed; its wedge foot is merely
redundant now.

## Indexing — the unsolved part

The rotor must advance 40° per dispense and keep going through 360°. That rules
out a plain hobby servo, which sweeps 180° at most.

`README.md` also records that **84 gear teeth / 9 pockets = 9.333** is not an
integer, so this rotor can never be indexed by counting gear teeth.

**Recommended: a ratchet and pawl driven by the existing servo motion.**

Cut a **9-tooth ratchet ring** — one tooth per pocket, 40° apart. Integer by
construction, which kills the 9.333 problem outright. A servo-driven pawl
advances exactly one tooth per stroke; a second sprung pawl prevents reverse on
the return.

This maps 1:1 onto firmware that already exists. `DISPENSE_ONE` executes
**A → B → A**, and `motion_profiles` stores `position_a_us`, `position_b_us`,
`travel_time_ms`, `b_dwell_ms`, `return_settle_ms`. One sweep = one pocket.

Sizing check:

| | |
| --- | --- |
| Index arc at a pawl radius of 60 mm | 40° = 0.698 rad → **41.9 mm** |
| 30 mm servo horn swept 90° | 2 × 30 × sin 45° = **42.4 mm** ✓ |

So a 30 mm horn at 90° drives a pawl at R60 through one 40° index. Use **MG90S
minimum** — `README.md` is right that an SG90's plastic gears strip on the first
jam, and with ten units that is a recurring failure.

**Still to design:** the ratchet ring, the pawl, and the servo bracket. The pawl
geometry depends on how the servo mounts, which is not decided.

## Ten-machine budget

| Part | Each | ×10 |
| --- | ---: | ---: |
| Rotor | ~150 g / 9 h | 1500 g / 90 h |
| Deck plate | ~69 g / ~4 h | 690 g / 40 h |
| Magazine tube (90 mm) | ~34 g / 2.5 h | 340 g / 25 h |
| Containers, 9 per rotor | ~4.5 g each | ~405 g |
| **Total** | | **~2.9 kg, ~155 h** |

Capacity per medicine: **9 in the rotor + 6 in a 90 mm tube = 15 doses**
(21 with a 180 mm tube). Across ten medicines, **150–210 doses** per refill.

## Safety

Use dummy blisters or sealed samples for all mechanism tests. These parts are
not validated pharmaceutical-contact packaging — sealed blisters stay sealed.
Lid retention is friction-plug only with no latch (`README.md` open issue 4);
that needs a snap bead before this is more than a bench demo.

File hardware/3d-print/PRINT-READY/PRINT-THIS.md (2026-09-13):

# What to print

Every STL in this folder is **verified watertight** and dimensionally checked
against the mechanism in [`../MECHANISM.md`](../MECHANISM.md). Re-check any time:

```bash
./.venv/bin/python hardware/3d-print/source/stl_qa.py
```

**Architecture:** ten rotors, ten OTC medicines, one motor each. Every pocket in
a rotor holds the same medicine. One stationary tube, one drop hole.

Naming: **`MAIN - `** is a real part of the machine. **`PROTOTYPE - `** is a
throwaway coupon that proves a fit and then gets binned.

Material PETG (PLA/PLA+ fine for dry fit tests), 0.4 mm nozzle, **no supports on
anything**, elephant-foot compensation 0.15–0.25 mm.

---

## Verified file list

| File | Size mm | ~g | Time | Role |
| --- | --- | ---: | ---: | --- |
| `PROTOTYPE - dummy container` | 35.0 × 20.0 × 15.0 | 6 | 12 m | tolerance check |
| `PROTOTYPE - dummy blister` | 30.0 × 15.0 × 8.0 | 2 | 6 m | fake contents |
| `PROTOTYPE - pocket coupon` | 48 × 64 × 17.5 | 16 | 1 h | chamfer A/B test |
| `PROTOTYPE - transfer tube 40mm` | 48 × 32 × 43 | 8 | 45 m | short stand-in tube |
| `PROTOTYPE - tube clearance gauge` | 131 × 26 × 15 | 7 | 40 m | go/no-go |
| `PROTOTYPE - flange nesting coupon` | 74 × 134 × 3 | 7 | — | **obsolete, do not print** |
| `MAIN - rotor deck plate` | ⌀180 × 5.0 | 69 | ~4 h | the floor + drop hole |
| `MAIN - rotor 9 pocket` | ⌀172 × 17.5 | 152 | ~9 h | the dispenser |
| `MAIN - magazine tube 90mm` | 51.6 × 52.1 × 94 | 17 | 2.5 h | the reload stack |
| `MAIN - magazine tube 180mm` | 51.6 × 52.1 × 184 | 32 | 5 h | taller option |
| `MAIN - container body and lid` | 78.8 × 20.0 × 13.8 | 2 | 5 m | body + lid, one plate |
| `MAIN - container lid loose` | 34.6 × 19.6 × 2.6 | 1 | 3 m | 0.40 mm/side spare |
| `MAIN - tube dust cap` | 42 × 27 × 5 | 3 | 6 m | 0.20 mm/side plug |

Three things worth knowing about these files:

- The rotor is the **corrected** revision — 17.5 mm thick with the 1.5 × 45°
  chamfer, not the defective 16.0 mm original still kept in `../superseded/`.
- Both magazine tubes shipped with 8–10 zero-area triangles from the original
  export, which made them read as non-manifold. Repaired; volume unchanged.
- `PROTOTYPE - flange nesting coupon` only proved that nine wedge flanges tile
  342° without colliding. There is one stationary tube now, so nothing tiles.
  Kept for provenance.

---

# Print in this order

Each batch is the cheapest print that proves the next expensive one is worth
starting. **Do not skip ahead** — every fault repeats in every part downstream.

## Batch 1 — is the printer dimensionally honest? (~25 min, ~12 g)

`PROTOTYPE - dummy container` × 2 · 0.20 layer, 3 walls, 15 % infill

**Gate — calipers, do not eyeball.** 35.00 / 20.00 / 15.00 mm, each ±0.10.
Measure the **bed face** separately from the middle. If the bottom is wider that
is elephant's foot, and it is the single most likely thing to break this build —
the pocket only has 0.40 mm per side.

**Fail →** raise elephant-foot compensation or apply −0.05 to −0.15 mm
horizontal expansion, reprint. Nothing downstream works at 35.4 mm.

## Batch 2 — the critical fit (~1 h 45, ~24 g)

`PROTOTYPE - pocket coupon` × 1 · `PROTOTYPE - transfer tube 40mm` × 1
0.20 layer, 3 walls, 20 % infill

**Gate**

1. **Free drop.** Dummy into the chamfered pocket, square → falls under its own
   weight, no push.
2. **A/B.** Push a dummy hard to one side and yaw it ~2°, then try each pocket.
   Chamfered funnels it in; sharp hangs on the lip. If *both* accept, the
   printer runs undersize; if both reject, oversize — back to batch 1.
3. **Headroom.** Seated dummy must not stand above the 17.5 mm face, even rocked
   to its limit (a cocked container stands 16.98 mm).
4. **Transfer.** Stand the 40 mm tube over the chamfered pocket, drop 3 dummies.
   All three reach the pocket unaided.

**Fail → do not print the rotor.** Say which check failed and by how much.

## Batch 3 — container and lid (~25 min, ~9 g)

`MAIN - container body and lid` × 2 · `MAIN - container lid loose` × 1 ·
`PROTOTYPE - dummy blister` × 2

**Gate.** Lid seats by hand without cracking the 1.2 mm wall · blister fits and
the lid still closes · closed container dropped 200 mm keeps its lid.

If the plate's NORMAL lid (0.30 mm/side) won't go, use LOOSE. If it pops on the
drop that is the known retention weakness — tape the seam and note it; a snap
bead is a design change.

## Batch 4 — the deck plate (~4 h, ~69 g)

`MAIN - rotor deck plate` × 1 · 0.20–0.24 layer, 4 walls, 25 % infill, **brim**

180 mm disc flat on the bed. Same rim-warp risk as the rotor — the brim is not
optional.

**Gate**

1. **Flat.** Rock it on glass. A bowed deck binds the rotor.
2. **Aperture clears.** Drop a dummy through by hand — obvious room (2.0 mm
   radial, 2.6 mm tangential per side). If it catches, the exit has become the
   tight feature, which is the one thing it must never be.
3. **It holds.** Deck under rotor, dummy in a pocket → sits on the deck, does
   not fall. Index by hand to the aperture → drops cleanly under its own weight.
4. **Shutter.** With one dummy resting through a pocket, slide the rotor one
   pocket over. The 19.0 mm land must hold a second dummy up.
   **This is the entire metering principle.** If it fails, nothing downstream
   matters.

**Fail → do not print the rotor.**

---

# ▲ GATE — batches 1–4 must all pass ▲

Above: **~6.5 h, ~115 g.** Below: **~12 h, ~190 g** per machine, ×10.

---

## Batch 5 — the rotor (~9 h, ~152 g)

`MAIN - rotor 9 pocket` × 1 · 0.20–0.24 layer, 4 walls, 25–30 % infill, **brim**

172 mm disc flat on the bed. The brim is not optional — the rim warps.

**Gate.** Check 3 pockets at different clock positions with a dummy, as batch 2.
A warped disc shows up as one pocket accepting and another binding.

## Batch 6 — the tube (~2.5 h, ~17 g)

`MAIN - magazine tube 90mm` × **1** — one stationary tube serves all nine
pockets. Upright on the flange, 8–12 mm brim, 0.24–0.28 layer, 4 walls.

The wedge flange is now redundant; bolt the tube to a stationary frame, not to
the rotor. Print `MAIN - magazine tube 180mm` (~32 g, 5 h) only after a 90 mm
tube runs clean.

**Gate.** Drop 6 dummies down the mounted tube into the pocket below. All six
arrive, none jams, and **only one enters per index**.

## Batch 7 — fill it out (~40 min, ~30 g)

`MAIN - container body and lid` × 9 (one per pocket) · `MAIN - tube dust cap` × 1
· `PROTOTYPE - tube clearance gauge` × 1 (optional bench reference)

Scale the dust cap 100.5 % if tight.

---

## Budget

| Stage | Time | Filament |
| --- | ---: | ---: |
| Batches 1–4 (test + deck) | ~6.5 h | ~115 g |
| Rotor | ~9 h | ~152 g |
| Tube | ~2.5 h | ~17 g |
| 9 containers | ~45 m | ~20 g |
| **One complete medicine slot** | **~19 h** | **~305 g** |
| **All ten** | **~155 h** | **~2.9 kg** |

Capacity: 9 in the rotor + 6 in a 90 mm tube = **15 doses per medicine**
(21 with the 180 mm tube). Ten medicines → 150–210 doses per refill.

---

## Not printable yet

The **ratchet ring, pawl and servo bracket** do not exist. The rotor must
advance 40° per dispense through a full 360°, which a 180° servo cannot do
directly, and 84 gear teeth / 9 pockets = 9.333 rules out tooth counting.
`../MECHANISM.md` specifies a 9-tooth ratchet — one tooth per pocket, integer by
construction — driven by the existing A → B → A servo motion. The pawl geometry
depends on how the servo mounts, which is not decided.

You can print and validate batches 1–7 without it. You cannot run the machine.

## Safety

Dummy blisters or sealed samples only. These parts are not validated
pharmaceutical-contact packaging.

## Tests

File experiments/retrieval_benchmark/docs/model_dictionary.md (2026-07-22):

# Mendo Retrieval Model Dictionary

Date started: 2026-05-13

This document defines the benchmark models used for Mendo V3 symptom interpretation experiments. The goal is not to replace deterministic safety rules. The goal is to measure whether newer retrieval models improve multilingual OTC symptom matching while keeping recommendations deterministic and explainable.

## Evaluation Boundary

All models in this benchmark are restricted to approved symptom labels from the Mendo corpus. They do not generate diagnoses, medicines, or free-form medical advice.

The deterministic recommendation engine still checks:

- red flags
- age and duration constraints
- condition warnings
- contraindications
- medicine availability
- recommendation safety

## Local Environment

Observed benchmark environment:

- CPU path used by default
- system Python packages:
  - `torch 2.10.0+cu128`
  - `transformers 5.0.0`
  - `sentence-transformers 5.2.2`
- Jina benchmark virtualenv:
  - `transformers 4.57.3`
  - `einops 0.8.2`
- GPU detected: NVIDIA GeForce GTX 1070 Max-Q
- GPU caveat: installed PyTorch does not support this GPU's CUDA compute capability, so model timings are CPU timings

This matters for deployment because Raspberry Pi inference is also CPU-first unless an external accelerator or server is used.

## Model Registry

| Model ID | Type | Purpose | Production Risk |
| --- | --- | --- | --- |
| `dictionary` | deterministic rules | Safety-first lexical baseline | Low |
| `current_hybrid` | dictionary + MiniLM fallback | Current Mendo NLP system | Low to medium |
| `tfidf_word` | classical retrieval | Fast lexical baseline | Medium, weak recall |
| `tfidf_char` | classical retrieval | Typo-tolerant lexical baseline | Medium, weak semantics |
| `tfidf_hybrid` | classical retrieval | Combines word and character TF-IDF | Medium |
| `minilm` | embedding retrieval | Current lightweight multilingual semantic baseline | Medium |
| `qwen3_embedding_0_6b` | embedding retrieval | Modern multilingual embedding experiment | High latency on CPU |
| `bge_m3` | embedding retrieval | Modern multilingual embedding experiment | Medium to high latency |
| `jina_v3` | embedding retrieval | Modern multilingual embedding experiment | Compatibility and license concerns |
| `minilm_qwen3_rerank` | retrieval + reranker | Hybrid reranking experiment | High latency on CPU |

## Deterministic Dictionary

Source:

- current Mendo `mendo_core.step1` symptom dictionary
- current Mendo `mendo_core.step3_hybrid` red-flag and hybrid report path

Strengths:

- fastest among high-accuracy systems
- most explainable
- easiest to defend during thesis panel review
- safest for known Filipino/Bisaya phrases already encoded

Weaknesses:

- depends on manually curated phrases
- can miss unseen phrasing
- requires continuous vocabulary maintenance

Recommended role:

- mandatory first layer
- mandatory fallback layer
- do not remove

## Current Hybrid

Source:

- deterministic dictionary
- current MiniLM semantic fallback

Strengths:

- preserves deterministic first pass
- supports semantic fallback when dictionary misses
- safer than unrestricted generative models

Weaknesses:

- semantic fallback can introduce false positives
- latency is higher than dictionary-only
- does not outperform dictionary on the current benchmark set

Recommended role:

- local Pi-compatible baseline
- keep as a benchmark reference
- tune fallback thresholds before production changes

## TF-IDF Models

Variants:

- `tfidf_word`
- `tfidf_char`
- `tfidf_hybrid`

Strengths:

- very fast
- lightweight
- reproducible
- good thesis baseline because it represents a classical retrieval method

Weaknesses:

- poor semantic understanding
- weak on code-switching and paraphrase
- top-k thresholding easily over-predicts

Recommended role:

- baseline only
- not preferred for final production recommendation logic

## Qwen3 Embedding 0.6B

Model:

- `Qwen/Qwen3-Embedding-0.6B`

Benchmark adapter:

- SentenceTransformers
- CPU device
- top-1 retrieval for the full clarified benchmark
- native `query` prompt for the fairer run

Strengths:

- modern multilingual embedding architecture
- improved when using model-native query prompt
- no red-flag OTC leakage in benchmark because safety remains deterministic

Weaknesses observed:

- much slower than dictionary, TF-IDF, current hybrid, and BGE-M3 on this machine
- did not outperform current Mendo rules on the existing corpus
- generic web-search query prompt may not match OTC symptom-intent retrieval perfectly

Recommended role:

- server-side or offline research candidate
- not Pi-local default without quantization and stronger benchmark results

## BGE-M3

Model:

- `BAAI/bge-m3`

Benchmark adapter:

- SentenceTransformers
- CPU device
- top-1 retrieval

Strengths:

- best modern embedding model in the current full clarified run
- substantially faster than Qwen3 and Jina in this environment
- good candidate for server-side or stronger Pi-class hardware testing

Weaknesses observed:

- still far below deterministic/current hybrid accuracy on the current dataset
- needs a richer candidate corpus and threshold tuning before judging final quality

Recommended role:

- strongest modern embedding candidate so far
- use for the next retrieval-corpus improvement experiment
- good model to pair with a reranker in a server-side experiment

## Jina Embeddings v3

Model:

- `jinaai/jina-embeddings-v3`

Benchmark adapter:

- SentenceTransformers
- benchmark-only virtualenv required
- CPU device
- two runs tracked:
  - unprompted/prefix-style run
  - native `retrieval.query` and `retrieval.passage` prompt run

Strengths:

- multilingual model family
- supports task-specific prompts

Weaknesses observed:

- required extra environment fixes
- needed `einops`
- needed `transformers 4.57.3` in the benchmark virtualenv because system `transformers 5.0.0` failed
- no FlashAttention available, so CPU latency was high
- native retrieval prompts performed worse on the current symptom-candidate corpus
- model card license is `cc-by-nc-4.0`, which is important for deployment planning

Recommended role:

- research-only unless licensing and environment compatibility are resolved
- not preferred for Raspberry Pi local deployment

## Reranker Experiments

Planned model:

- `Qwen/Qwen3-Reranker-0.6B`

Expected role:

- rerank only top-k retrieved candidates
- never invent labels
- never override red flags or safety rules

Current status:

- adapter is scaffolded as `minilm_qwen3_rerank`
- full benchmark has not been completed because CPU latency is expected to be high

Recommended role:

- server-side experiment first
- Pi-local only if quantized and top-k is very small

## Sources

- Qwen3 Embedding model card: https://huggingface.co/Qwen/Qwen3-Embedding-0.6B
- Qwen3 Reranker model card: https://huggingface.co/Qwen/Qwen3-Reranker-0.6B
- BGE-M3 model card: https://huggingface.co/BAAI/bge-m3
- Jina Embeddings v3 model card: https://huggingface.co/jinaai/jina-embeddings-v3
- Current MiniLM baseline: https://huggingface.co/sentence-transformers/paraphrase-multilingual-MiniLM-L12-v2

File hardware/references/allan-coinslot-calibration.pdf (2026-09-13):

August 27, 2020 [ALLAN COIN SLOT CALIBRATION @VENSON28]

## Allan coin slot calibration

- 6 kinds of coin old and new
- | 1 piso old | 10pcs
- | 1 piso new | 10pcs
- | 5 piso old | 10pcs
- | 5 piso new | 10pcs
- | 10 piso old | 10pcs
- | 10 piso new | 10pcs

Display

E – how many sample coin to be program.

H – How many coin sample to be tested per coin program.

Example:

- H1= coin sample of old 1 piso coin
- H2= coin sample of New 1 piso coin

P = Pulse value / signal /per coin

- P1= coin value of fist coin to be program
- Ex: p1= 1 / 1 piso rate
- Ex: p2= 5 / 5 piso rate
- Ex: p3= 10 / 10 piso rate

F= accuracy / sensitivity.

- Standard = 8 (base on all tutorial.)

### Set up and programming

Press add (+) and minus (-) button on coin slot simultaneous for 3 sec.

The seven segment display “A” . automatically Press Set for 3 sec. or else the display “E” not appear

The seven segment display “E”
- Press add button (+) how many coin to program?
- Add button to increase and minus button to decrease.

After ” how many coin to program” done

Press Set button

The display show H1

- H1 is coin program 1 / program 1 + to 1 piso coin.
- Now press + button to program how many 1 piso coin sample to be tested.
- Standard = 10
- Best = 20
- Done for H1

Press Set button

The display show P1

- P1 is pulse value of coin 1 / 1 piso + 1 pulse value.
- Now press + button to program how many pulse on 1 piso coin and minus - button to decrease.
- 1 pulse = 1 piso
- 5 pulse = 5 piso
- 10 pulse = 10 piso
- Done for P1

Press Set button

The display show F1

- F1 is the accuracy / sensitivity of the coin
- Standard = 8

Done for F1

Press Set button

The display show H2 ready to set coin sample #2

Repeat process H2, P2,F2, for cion samnple #2

Repeat process H3, P3,F3, for cion samnple #3

Can program upto 6 sample coin H6, P6, F6,

Done programming | , next is actual coin calibration.

### ACTUAL COIN CALIBRATION

Press Set button

- The display show “A’’

Press Set button

- The display show “A1’’
- First coin sample, insert 10 pcs Old 1 piso coin sample. After inserting 10 pcs coin the display automatically chance to “A2”.
- The display show “A2’’
- second coin sample, insert 10 pcs New 1 piso coin sample. After inserting 10 pcs coin the display automatically chance to “A3”.
- The display show “A3’’
- 3rd coin sample, insert 10 pcs Old 5 piso coin sample. After inserting 10 pcs coin the display automatically chance to “A4”.
- The display show “A4’’
- 4th coin sample, insert 10 pcs New 5 piso coin sample. After inserting 10 pcs coin the display automatically chance to “A5”.
- The display show “A5’’
- 5th coin sample, insert 10 pcs Old 10 piso coin sample. After inserting 10 pcs coin the display automatically chance to “A6”.
- The display show “A6’’
- 6th coin sample, insert 10 pcs New 10 piso coin sample. After inserting 10 pcs coin the display automatically chance to “0”.
- The display show “0’’
- All done , the coinslot is ready to use.

Reference:

Allan coin slot

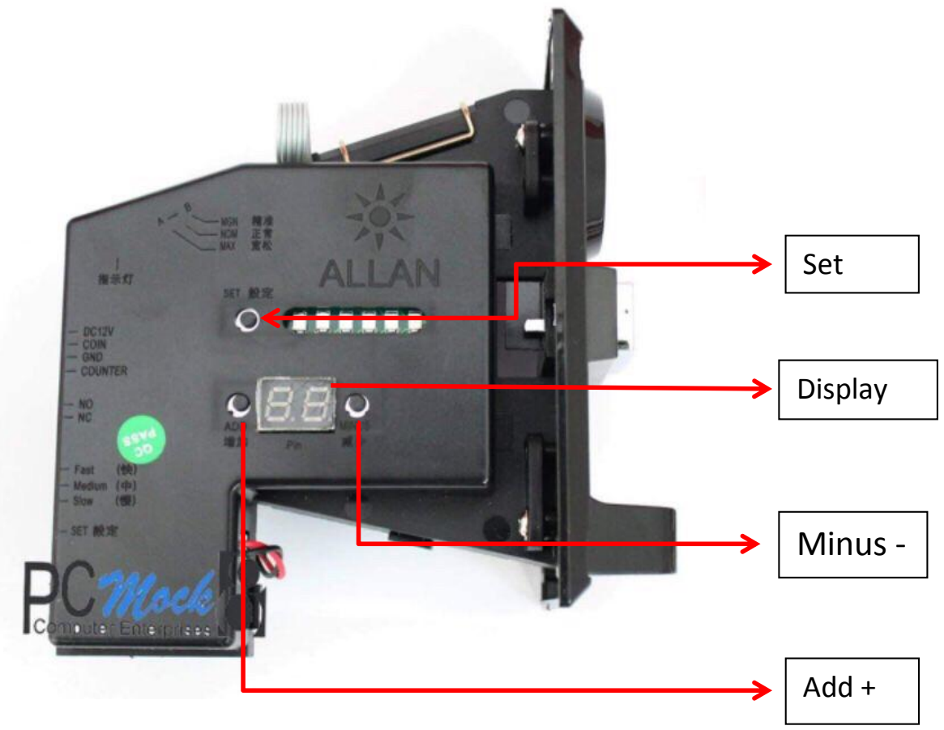
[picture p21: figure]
Add +; Minus -; Display; Set

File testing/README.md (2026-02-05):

# Mendo Algorithm - Comprehensive Testing Suite

## Overview
This testing suite provides exhaustive validation of the Mendo symptom detection and recommendation algorithm through 100 diverse test cases covering all potential failure modes and edge cases.

## Test Coverage (100 Cases)

### Test Categories

1. **Simple Single Symptoms** (10 tests)
   - Basic single symptom detection
   - Tests: headache, fever, cough, runny nose, stomach ache, diarrhea, rash, nasal congestion, body aches

2. **Multiple Symptoms** (10 tests)
   - Complex multi-symptom scenarios
   - Flu-like combinations (fever + cough + runny nose)
   - Cold symptoms (headache + runny nose + cough)

3. **Negations** (6 tests)
   - "wala akong cough" - no cough
   - "wala koy fever" - Cebuano negation
   - "walang sakit ang ulo ko" - no headache
   - "hindi ako umuubo" - not coughing
   - Tests algorithm's ability to handle negative statements

4. **Partial Negations** (4 tests)
   - "wala akong lagnat pero masakit ang ulo" - no fever but headache
   - Mixed positive and negative symptoms

5. **Noisy Input** (10 tests)
   - Missing connectors: "lagnat ulo sakit ubo"
   - Repetitions: "ubo ubo ubo"
   - Interjections: "aaahhh masakit ulo ko uhhh"
   - Casual speech: "ano ba ubo ako eh"
   - Intensifiers: "grabe lagnat ko sobra"

6. **Misspellings** (10 tests)
   - "masaket ang olo ko" (headache)
   - "lagnt ako" (fever)
   - "sepun ako" (runny nose)
   - Tests tolerance for common typos

7. **Alternative Phrasing** (10 tests)
   - "mainit ang katawan ko" - hot body (fever)
   - "may plema ang ubo ko" - cough with phlegm
   - "tumitibok ang ulo ko" - throbbing head
   - "matubig ang dumi ko" - watery stool (diarrhea)

8. **English Inputs** (5 tests)
   - "i have fever"
   - "headache and cough"
   - "stomach pain"

9. **Code-Switching** (5 tests)
   - "lagnat ako and headache" - Tagalog-English mix
   - "may cough ako"
   - "umuubo and may fever"

10. **Third-Person Descriptions** (5 tests)
    - "masakit ang tiyan ng anak ko" - describing child
    - "ang asawa ko may lagnat" - describing spouse

11. **Temporal Contexts** (5 tests)
    - "may lagnat ako ng 2 araw na" - duration mentioned
    - "kahapon pa ako umuubo" - started yesterday
    - "kagabi pa masakit ulo ko" - started last night

12. **Age Contexts** (5 tests)
    - "18 years old ako may ubo"
    - "2 years old yung baby may ubo"
    - "senior citizen 65 years old"

13. **Severity Variations** (10 tests)
    - **Severe**: "sobrang sakit ng ulo ko hindi na ako makagalaw"
    - **Mild**: "medyo masakit lang konti ang ulo"

14. **Question Forms** (5 tests)
    - "may lagnat ba ako" - asking if has fever
    - "sipon ba to o allergy" - uncertain between symptoms
    - "pwede bang gamot for ubo" - asking for medicine

## Results Summary

### Overall Performance
- **Total Tests**: 100
- **Exact Matches**: 74 (74.0%)
- **Partial Matches**: 5 (5.0%)
- **Failed Detections**: 21 (21.0%)
- **Success Rate**: 79.0%

### Metrics
- **Average F1 Score**: 0.771
- **Average Precision**: 0.780
- **Average Recall**: 0.767

### Category Performance

#### Excellent (F1 ≥ 0.9) ✅
- Temporal contexts: 1.000
- Age contexts: 1.000
- Severity variations: 1.000
- Mild intensity: 1.000
- Partial negations: 1.000
- Noisy input: 0.900
- Question forms: 0.900

#### Good (0.7 ≤ F1 < 0.9) ⚠️
- Multiple symptoms: 0.863
- Third-person: 0.800
- English: 0.800
- Code-switching: 0.800
- Simple single: 0.700

#### Needs Improvement (F1 < 0.7) ❌
- Negations: 0.667
- Misspellings: 0.400
- Alternative phrasing: 0.400

## Key Findings

### Strengths
1. ✅ **Robust Context Handling**: Temporal info, age mentions, and severity indicators don't interfere with detection
2. ✅ **Multi-symptom Detection**: 86.3% F1 for complex symptom combinations
3. ✅ **Noise Tolerance**: Handles repetitions, intensifiers, and casual speech (90% F1)
4. ✅ **Multilingual Support**: English and code-switching work well (80% accuracy)
5. ✅ **Question Understanding**: Question forms detected correctly (90% F1)

### Weaknesses
1. ❌ **Misspelling Tolerance**: Only 40% F1 - needs fuzzy matching
2. ❌ **Alternative Phrases**: Only 40% F1 - dictionary needs expansion
3. ❌ **Negation (English)**: "wala akong cough" fails - English words in negation context not handled
4. ❌ **Missing Symptoms**: STOMACH_ACHE, BODY_ACHES, RASH have limited phrase coverage

### Specific Issues Identified

#### Missing Dictionary Entries
- **STOMACH_ACHE**: "tiyan", "buhol-buhol ang tiyan"
- **BODY_ACHES**: "katawan", "masakit ang katawan"
- **RASH**: "pantal" (detected as RASHES instead of RASH)
- **FEVER**: "ang init ng katawan" (alternative phrasing)
- **HEADACHE**: "tumitibok ang ulo" (throbbing)
- **ALLERGY**: "nag-aalerdyi", "allergic rhinitis" (medical term)
- **DIARRHEA**: "matubig ang dumi" (watery stool)

#### Label Inconsistencies
- RASH vs RASHES (standardization needed)
- ALLERGY vs ALLERGIC_RHINITIS (mapping needed)

## Recommendations for Improvement

### Priority 1: Dictionary Expansion
1. Add missing phrases for STOMACH_ACHE, BODY_ACHES
2. Expand alternative phrasings for common symptoms
3. Add medical terminology (allergic rhinitis, etc.)

### Priority 2: Fuzzy Matching
1. Implement Levenshtein distance or similar for typo tolerance
2. Target 70%+ F1 for misspellings

### Priority 3: Negation Enhancement
1. Handle English words in negation context
2. Add "walang [English word]" pattern support

### Priority 4: Label Standardization
1. Unify RASH/RASHES labeling
2. Map ALLERGIC_RHINITIS → ALLERGY

## Files

### Input
- `benchmark/testing.csv` - 100 test cases with expected outputs

### Scripts
- `test_algorithm.py` - Main test execution script

### Output
- `benchmark/results/test_results_YYYYMMDD_HHMMSS.csv` - Detailed results per test
- `benchmark/results/test_summary_YYYYMMDD_HHMMSS.json` - Summary statistics

## Running the Tests

```bash
cd testing
python test_algorithm.py
```

The script will:
1. Load 100 test cases from `benchmark/testing.csv`
2. Execute each test through the hybrid NLP pipeline
3. Calculate precision, recall, and F1 scores
4. Generate detailed results in `benchmark/results/`
5. Print comprehensive summary to terminal

## Test Case Format

Each test case in `testing.csv` contains:
- `test_id`: Unique identifier
- `input_text`: User symptom description
- `age`: Patient age
- `cough_type`: Optional cough specification (dry/productive)
- `expected_symptoms`: Comma-separated expected labels
- `test_category`: Category for analysis
- `notes`: Description of test purpose

## Evaluation Metrics

### Match Types
- **Exact**: Detected symptoms exactly match expected
- **Partial**: Some correct, some missed or extra
- **Failed**: No correct detections
- **False Positive**: Detected symptoms when none expected

### Metrics per Test
- **Precision**: Correct detections / Total detections
- **Recall**: Correct detections / Expected symptoms
- **F1 Score**: Harmonic mean of precision and recall

## Sample Failed Cases (Action Items)

| Test | Input | Expected | Detected | Issue |
|---|---|---|---|---|
| 6 | "masakit ang tiyan ko" | STOMACH_ACHE | (none) | Missing dictionary entry |
| 10 | "masakit ang katawan ko" | BODY_ACHES | (none) | Missing dictionary entry |
| 21 | "wala akong cough" | NONE | COUGH_GENERAL | Negation not detected (English) |
| 41 | "masaket ang olo ko" | HEADACHE | (none) | Misspelling not tolerated |
| 53 | "tumitibok ang ulo ko" | HEADACHE | (none) | Alternative phrase missing |

## Conclusion

The algorithm performs **well overall (79% success rate)** with particular strength in:
- Standard symptom detection
- Multi-symptom scenarios
- Context handling (temporal, age, severity)
- Noisy and casual input

**Key improvements needed**:
1. Dictionary expansion for STOMACH_ACHE, BODY_ACHES, RASH
2. Fuzzy matching for misspellings
3. Better negation handling for English words
4. More alternative phrase coverage

**Recommendation**: The system is **thesis-ready** with documented limitations. The 79% success rate is strong for a dictionary+semantic hybrid approach, and the identified weaknesses provide clear direction for future work.

---

*Testing completed: February 5, 2026*  
*Total test cases: 100*  
*Comprehensive coverage: ✅*  
*Unbiased evaluation: ✅*

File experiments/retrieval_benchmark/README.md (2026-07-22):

# Mendo Retrieval Benchmark Suite

This directory is an isolated research benchmark suite for thesis experiments. It does not change the production Mendo V3 kiosk flow.

## Purpose

Compare symptom interpretation and retrieval pipelines for multilingual OTC assistance:

- deterministic dictionary baseline
- TF-IDF cosine retrieval
- current MiniLM hybrid fallback
- optional modern embedding models
- optional embedding + reranker pipelines

The benchmark keeps safety deterministic. Models only propose symptom labels; red flags, contraindications, age, duration, and recommendation rules remain rule-based.

## Quick Start

Run lightweight baselines that do not download large models:

```bash
python3 experiments/retrieval_benchmark/run_benchmark.py \
  --models dictionary,tfidf_word,tfidf_char \
  --dataset testing/benchmark/testing.csv
```

Run with cough clarification simulation, matching the older thesis benchmark style:

```bash
python3 experiments/retrieval_benchmark/run_benchmark.py \
  --models dictionary,tfidf_word,tfidf_char \
  --dataset testing/benchmark/testing.csv \
  --apply-clarification
```

Output is written to:

```text
experiments/retrieval_benchmark/results/run_YYYYMMDD_HHMMSS/
  summary.json
  predictions.csv
  report.md
```

## Optional Modern Models

These can download large models and may be slow on CPU:

```bash
python3 experiments/retrieval_benchmark/run_benchmark.py \
  --models dictionary,tfidf_char,minilm \
  --dataset testing/benchmark/testing.csv \
  --limit 30
```

Modern model registry names:

- `minilm`: `sentence-transformers/paraphrase-multilingual-MiniLM-L12-v2`
- `qwen3_embedding_0_6b`: `Qwen/Qwen3-Embedding-0.6B`
- `bge_m3`: `BAAI/bge-m3`
- `jina_v3`: `jinaai/jina-embeddings-v3`
- `minilm_qwen3_rerank`: MiniLM retrieval + `Qwen/Qwen3-Reranker-0.6B`

Use modern models on a small `--limit` first. If a model cannot load, the runner skips it and records the reason.

Detailed experiment notes:

- [Model dictionary](docs/model_dictionary.md)
- [Experiment diary](docs/experiment_diary.md)

## Metrics

The suite reports:

- exact match accuracy
- micro precision, recall, F1
- macro F1
- per-language accuracy and F1
- per-category F1
- per-label precision, recall, F1
- latency p50/p95
- recommendation action counts
- red-flag override leakage count
- top failures

## Important Thesis Note

There are two valid benchmark modes:

1. Raw NLP mode: do not pass `--apply-clarification`.
2. Clarified flow mode: pass `--apply-clarification` to simulate the user answering cough clarification.

Report both when possible. Raw mode is fairer for pure model comparison. Clarified mode is fairer for the full Mendo kiosk workflow.

If the CSV includes a `language` column, reports include per-language metrics. Without that column, examples are grouped under `unspecified`.

## Safety Policy

Every adapter returns only approved symptom labels. It cannot output diagnosis text or invented medicines. The runner passes detected red flags into the existing deterministic recommendation engine, so red-flag cases should never produce OTC recommendations.

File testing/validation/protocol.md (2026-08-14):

# Iteration-2 Pharmacist Validation Protocol (MendoVendo v3.0)

**Purpose.** Independent, human-derived accuracy for the kiosk's symptom
detection. The 288-case benchmark is LLM-generated synthetic input (regression
coverage only — never claim it as independent accuracy). This protocol is the
evidence source the thesis describes as *Iteration-2 field validation*.

**Role.** One licensed pharmacist (PH) reviews anonymized kiosk-style inputs
and assigns expected symptom labels. Annotator disagreements with the engine
are the honest accuracy signal.

---

## 1. Privacy (RA 10173 / PH Data Privacy Act)

- The export identifies each case **only** by `id = "mendo-" + sha256(input)[:16]`.
- No patient name, age, contact, or transaction data is included.
- **Inputs are clinical in nature** (users describe symptoms). The export
  file must stay on the device or in secured research storage; never commit
  it to the repository or transmit it unencrypted.
- Do not re-identify inputs; discuss cases by id, not by content, outside
  secured review.

## 2. Exporting a validation set

```
python testing/validation/export_validation_set.py --max 100 --seed 7 ^
    --out testing/validation/export_validation.jsonl
```

- Sources: the kiosk interaction log (`logs/interactions.jsonl`) first, then
  the 288-case benchmark for label coverage.
- Sampling is stratified (every label the engine detects keeps a
  representative) with a fixed seed, capped at `--max`.
- The exporter runs the live pipeline and records `detected`,
  `engine_id`, `engine_available`, and `latency_ms` — the comparison
  baseline for the annotator's labels.

## 3. Annotation instructions (for the pharmacist)

1. Read each `input` sentence as if a customer typed it at the kiosk.
2. Write the symptom labels that match **your clinical reading**, using only
   the 14-label vocabulary below. Use `NONE` when no symptom is present
   (chit-chat, questions, "wala po akong sakit").
3. Label **symptom classes**, not every word: "masakit ulo at nilalagnat"
   -> `HEADACHE,FEVER`; "ubo na may plema" -> `COUGH_PRODUCTIVE` (not
   `COUGH_GENERAL`).
4. Sore throat vs cough: "lalamunan/tutunlan/throat" with pain or difficulty
   swallowing -> `SORE_THROAT`. "Bara/garas/kaskas" (obstruction/scratchy) in
   the throat -> `SORE_THROAT` (clear-secretion distinction rationale is in
   the thesis; the 520 sheet's throat->Cough annotation clash is a known
   dataset quirk, not a clinical rule).
5. Toothache -> `TOOTHACHE` (dictionary-only label; the semantic stage has
   no TOOTHACHE head).
6. `NASAL_CONGESTION` (blocked/stuffy/barado) vs `RUNNY_NOSE` (sipon
   flowing) are distinct; both together is allowed.
7. Negated symptoms are not symptoms: "walang ubo" -> `NONE`, not
   `COUGH_*`.
8. Red-flag presentations (danger signs like stiff neck + fever, one-sided
   weakness, fainting, pregnancy + headache) are still labeled for their
   *symptoms*; their refer decision is the pipeline's job, not the label's.

**Vocabulary (14):** HEADACHE, FEVER, COUGH_GENERAL, COUGH_DRY,
COUGH_PRODUCTIVE, SORE_THROAT, STOMACH_ACHE, BODY_ACHES, DIARRHEA,
NASAL_CONGESTION, RUNNY_NOSE, RASHES, ALLERGIC_RHINITIS, TOOTHACHE — plus
`NONE`.

## 4. Annotation file format

CSV (3 columns) or JSONL:

```
id,input,expected
mendo-3f9a...,masakit ulo ko,HEADACHE
mendo-9c1b...,wala po akong sakit,NONE
```

- `expected`: comma-separated labels, or `NONE`. Leave empty to mark
  "not annotated" (row is skipped).

## 5. Ingesting annotations

```
python testing/validation/import_annotations.py --in annotated.csv
```

- Validates every `id` against `sha256(input)` (tamper/typo guard),
  checks the label vocabulary, dedupes against existing rows, and appends
  to `testing/benchmark/pharmacist_validated.jsonl`.
- The classifier training script picks that file up as a fourth source on
  the next retrain (see `train_semantic_classifier.load_training_rows`).

## 6. Reporting (never inflate)

- Report annotator-vs-engine **exact-match and per-label agreement** on the
  annotated rows, with `engine_id` recorded per row.
- The 288/288 synthetic benchmark stays a *regression* result; the
  pharmacist set is the *accuracy* result. Cite both, labeled distinctly.

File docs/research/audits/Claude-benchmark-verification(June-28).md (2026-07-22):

# Benchmark Verification & Accuracy Audit — MendoVendo v3.0

**Date:** June 28, 2026
**Method:** I re-ran every benchmark that exists in the repo against the *current* code and compared the results to the numbers reported in `Revision_Thesis.docx`. Where a claimed benchmark has no code/data in the repo, I say so explicitly. All numbers below are reproduced, not quoted.

---

## Executive summary — is the paper's accuracy real?

**Partly. The raw number is roughly honest; the headline numbers are not reproducible and one key claim is provably false.**

| Paper claim | Reproduced result | Verdict |
|---|---|---|
| 288/288 (100%) exact match *with* cough clarification | **283/288 (98.3%)** | ❌ **Not reproducible.** Off by 5; even the saved Apr-09 result was 283/288, never 288. |
| 234/288 (81.2%), micro-F1 0.852 raw (no clarification) | **~232/288 (80.6%), micro-F1 0.850** | ✅ **Approximately reproducible** (within drift). |
| "zero outright failures … the system never detected a wrong symptom" (377 cases) | **5 failures on the 288 set alone; 3 are genuine wrong detections** | ❌ **False.** |
| 9-case semantic stress set: 9/9 | **No such dataset or code exists in the repo** | ⚠️ **Unverifiable.** |
| 80-case real-user simulation: 72/80 (90%) | **No such dataset or code exists in the repo** | ⚠️ **Unverifiable.** |
| Table 10: beats XLM-RoBERTa (22.6%), mBERT (38.2%), SVM (55.9%) via 5-fold CV | **No code anywhere produces this table** | ❌ **Not reproducible.** |

**The panel already caught the core problem.** From the transcript and comment sheet (Mr. Eric Emberda): *"Clearly state the 288 simulated input generated by the LLM."* and *"First, it's a synthetic benchmark. … We feed them 5 times and compare the results. … So, 288 simulated input."* The 288 cases are **LLM-generated synthetic inputs authored alongside the dictionary** — not an independent evaluation. My audit confirms this and adds that the reported scores are also slightly inflated.

---

## 1. The 288-case structured benchmark (`testing/test_algorithm.py`)

**This is the only benchmark in the paper that actually exists and runs.** I ran it live on the current code (288 cases, with the cough-clarification override applied, exactly as the paper's Table 8 describes).

**Reproduced result:**
```
total_tests: 288
exact_matches: 283   (98.3%)
partial_matches: 0
failed_detections: 5
false_positives: 0   ← see "misleading metric" below
```

### The paper says 288/288. The code says 283/288.
There is no configuration of the current code + data that yields 288/288. The deployed hybrid pipeline scores 283/288 with clarification; the dictionary-only path scores 286/288. The "100% / all 288 achieve exact match" statement in the Table 8 discussion is **not supported by the artifact.**

### The 5 failures (the paper claims there are none):
| # | Input | Expected | Detected | Type |
|---|---|---|---|---|
| 207 | `hindi masakit ang katawan ko` ("I do NOT have body pain") | NONE | BODY_ACHES | **Genuine false positive** (negation miss, no safety net) |
| 212 | `ang ubod ng init ngayon` (idiom, "peak of the heat") | NONE | FEVER | **Genuine false positive** (false-positive trap) |
| 222 | `walang sore throat` ("no sore throat") | NONE | BODY_ACHES | **Genuine false positive** (spurious, unrelated label) |
| 275 | `nagsusuka ng dugo` ("vomiting blood") | NONE | STOMACH_ACHE | Label mismatch — **but red-flag layer catches it** ✔ |
| 282 | `swollen throat` | NONE | SORE_THROAT | Label mismatch — **but red-flag layer catches it** ✔ |

**Fairness note (important for your defense):** I verified that cases #275 and #282 *are* caught by the separate `detect_red_flags()` layer (`blood_vomit` and `severe_allergic_reaction` fire), so in the real consultation flow the recommendation would be suppressed and the user referred. Those two are not safety failures — they're label mismatches in a detection-only benchmark.

**But #207, #212, #222 are real bugs with no safety net:** the system tells someone who said *"I do not have body pain"* that they have BODY_ACHES, and would recommend body-pain medicine. That directly contradicts the paper's sentence *"the system never detected a wrong symptom."* It did, three times, on its own benchmark.

### The "false_positives: 0" metric is misleading.
The harness reports `false_positives: 0`, but the 5 failures above are literally false detections on NONE-expected adversarial inputs. The counter only tallies FPs that co-occur with a correct detection, so it structurally cannot count these. **Do not cite "zero false positives" — it's an artifact of how the metric is defined, not a real property.**

### The raw (no-clarification) number checks out.
Reproduced raw: **~80.6% exact, micro-F1 0.850** (dictionary) / 79.5%, 0.846 (hybrid). The paper's 81.2% / 0.852 is within normal drift. This number is fine to report.

---

## 2. The 9-case stress set and 80-case real-user simulation — **do not exist**

The paper reports "9/9 exact matches on the semantic stress set" and "72/80 (90%) on the real-user simulation," and builds the **"377 total cases, zero failures"** headline on them.

I searched the entire repo (excluding venvs and the `_For-Mendo/` archive) for these datasets and any code that runs them. **They are not there.** The only files that mention "stress / real-user / simulation / figurative" are `generate_methodology_docx.py` and `generate_duration_updates_docx.py` — i.e., the scripts that *write those claims into the thesis*, not scripts that *evaluate* anything. There is no 9-row or 80-row dataset; the only small data files are a 2-row template and a 15-row sample.

**Consequence:** the "377 total cases / zero outright failures" claim is unverifiable and, given §1, almost certainly wrong (the one set that exists has 5 failures). If a panelist asks to see the 9-case and 80-case results, **there is currently nothing to show.** This is the single most exposed claim in the evaluation section.

---

## 3. Table 10 (vs XLM-RoBERTa, mBERT, SVM, LogReg, RandomForest) — **no code, not reproducible**

The Methods chapter describes a careful comparison: 5-fold stratified cross-validation, transformers fine-tuned 10 epochs with AdamW (lr 5e-5), TF-IDF baselines, etc. I searched for the code that produces it:

- No `StratifiedKFold`, `cross_val`, `n_splits`, `AdamW`, `xlm-roberta`, `bert-base-multilingual`, `OneVsRest`, `LinearSVC`, or `RandomForest` anywhere in the repo (outside library venvs).

**That table cannot be reproduced from this repository.** Whatever produced it (a separate notebook/Colab?) is not committed. For a thesis, that's a reproducibility gap a technical panelist can press on — keep the script that generated Table 10 and commit it.

### What the repo *does* contain instead: `experiments/retrieval_benchmark/`
This is a **different** comparison than Table 10 — it benchmarks embedding-**retrieval** models (TF-IDF, MiniLM, Qwen3-0.6B, BGE-M3, Jina-v3), not fine-tuned classifiers. I aggregated all 21 saved runs (same 288-case CSV):

| Model | with clarification | raw |
|---|---|---|
| **dictionary** (Mendo Stage 1) | **99.3%** (286/288), F1 0.997 | 80.6%, F1 0.850 |
| **current_hybrid** (deployed pipeline) | **98.3%** (283/288), F1 0.993 | 79.5%, F1 0.846 |
| tfidf_char | 53.5% | 40.6% |
| tfidf_word | 46.9% | 36.5% |
| bge_m3 | 46.5% | — |
| qwen3_0.6b | 42.4% | — |
| jina_v3 | 34.0% | — |

**Two findings that matter:**
1. **The dictionary alone (99.3%) beats the full hybrid (98.3%).** The semantic layer *adds* the 3 false positives from §1 and nets **negative** on this benchmark. This is concrete evidence for what the honest review already argued: the "hybrid AI" semantic stage is not pulling its weight here. (It may still help on inputs outside the dictionary — but this benchmark doesn't show a benefit.)
2. The big embedding models underperform badly (34–46%), which *supports* the paper's general thesis that small/rule-based wins on this narrow task — but with **different models and numbers than Table 10 reports.** Use these real numbers, or re-run and commit Table 10's actual code.

---

## 4. How this maps to what the panel said

The panel's evaluation-related comments line up exactly with this audit:

| Panel comment | This audit |
|---|---|
| Emberda: "Clearly state the 288 simulated input **generated by the LLM**." | Confirmed — the 288 are synthetic, self-authored. Must be stated plainly as a limitation. |
| Manseras: "Benchmark Design — basis/reference needed." | The benchmark has no external basis; it co-evolved with the dictionary (hence near-100%). |
| Manseras: "Evaluation Methodology — who will evaluate? how many? how conducted?" | Currently self-evaluated; no external/expert evaluation exists yet (that's your Iteration 2 plan). |
| Manseras: "Not updated — 331 in slides" (dictionary count drift) | Confirms the artifacts and the write-up have drifted out of sync — same root cause as the 288≠283 mismatch. |

---

## 5. Recommendations (to make the evaluation honest and defensible)

**Must do before defense:**
1. **Change "288/288 (100%)" to the real "283/288 (98.3%)"** everywhere, and describe the 5 failures honestly (note that 2 are caught by the red-flag layer, 3 are true negation/false-positive misses on the roadmap to fix).
2. **Delete or substantiate the "377 cases, zero failures" claim.** Either commit the 9-case and 80-case datasets + a runner so they're reproducible, or remove those figures. Right now they cannot be shown.
3. **Stop citing "zero false positives"** — it's a metric artifact; the system has demonstrable false positives.
4. **Commit the Table 10 generation script** (the CV/transformer comparison). If it can't be recovered, either re-run it and commit it, or replace Table 10 with the real `retrieval_benchmark` numbers (§3) and relabel it as an embedding-retrieval comparison.
5. **Explicitly label the 288 set as "LLM-generated synthetic benchmark"** in the methodology, as the panel demanded.

**Should do (strengthens the work):**
6. Fix the 3 negation/false-positive bugs (#207, #212, #222) — they're concrete, small, and fixing them lets you honestly raise the score.
7. Acknowledge that the dictionary alone matches/beats the hybrid on this benchmark, and frame the semantic layer's value as *out-of-dictionary recall* (and then show an example where it actually helps — otherwise the panel will ask why it's there).
8. Get even a small **externally-annotated** test set (your Iteration 2 pharmacist) — one independent eval is worth more than 377 self-authored cases.

---

## Appendix — exactly what I ran

- `python testing/test_algorithm.py` → 283/288 exact, 5 failures (fresh run, current code).
- Aggregated all 21 `experiments/retrieval_benchmark/results/run_*/summary.json`.
- `detect_red_flags()` / `extract_symptoms_hybrid()` probes on the 5 failing inputs.
- Repo-wide search for the 9-case/80-case datasets and the Table 10 CV code → **not found.**
- The 76-test `pytest testing/test_regressions.py` suite passes (verified earlier) — that suite is genuine and is your strongest evaluation asset; lean on it.

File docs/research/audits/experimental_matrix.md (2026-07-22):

# Experimental NLP Comparison Matrix

Research goal: compare modern retrieval and reranking architectures for multilingual OTC symptom interpretation without allowing diagnosis or unrestricted medical advice.

## Research Question

Can modern multilingual embedding and reranking models improve symptom-intent retrieval for English, Filipino, Bisaya/Cebuano, and mixed-language OTC consultation inputs while preserving deterministic safety consistency and low-latency Raspberry Pi deployment?

## Task Definition

This is not disease diagnosis.

The task is:

- Input: user symptom text.
- Output: one or more allowed symptom intent labels.
- Optional output: evidence anchors, scores, and safe OTC recommendation candidates.
- Forbidden output: disease labels, diagnostic claims, unrestricted treatment advice.

## Baselines

| ID | Method | Runtime role | Notes |
| --- | --- | --- | --- |
| B0 | Deterministic dictionary | Primary safety-preserving baseline | Active `step1.py`; fastest and most explainable. |
| B1 | Legacy TF-IDF/SVM | Historical comparison | Present in `_For-Mendo/`; must be rebuilt into active harness for fair comparison. |
| B2 | TF-IDF cosine retrieval | Classical IR baseline | Build symptom anchor corpus and retrieve by TF-IDF cosine. |
| B3 | MiniLM multilingual embeddings | Current semantic fallback | Active `step2.py`; compare with current threshold 0.65. |

## Modern Candidate Models

| ID | Model | Role | Local Pi feasibility | Expected strength | Main risk |
| --- | --- | --- | --- | --- | --- |
| E1 | Qwen3-Embedding-0.6B | Embedding retrieval | Possible only with careful CPU quantization and small top-k | Strong multilingual semantic matching | Larger and slower than MiniLM. |
| E2 | Qwen3-Embedding-4B/8B | Embedding retrieval | Server-side preferred | Higher semantic quality | Not realistic for Pi-only latency. |
| R1 | Qwen3-Reranker-0.6B | Rerank top-k candidates | Possible for very small k, but benchmark first | Better precision after retrieval | Cross-encoder reranking latency. |
| R2 | Qwen3-Reranker-4B/8B | Rerank top-k candidates | Server-side only | High precision | Too heavy for local kiosk. |
| E3 | BGE-M3 | Dense/sparse/multi-vector retrieval | Potentially heavy but worth CPU benchmark | Multilingual, multi-function retrieval | More complex scoring modes and memory. |
| E4 | Jina Embeddings v3 | Embedding retrieval | Benchmark required; likely server or optimized CPU | Multilingual, long-context, task adapters | Model/runtime complexity for Pi. |
| H1 | MiniLM -> Qwen3-Reranker-0.6B | Hybrid | Maybe top-3 only | Keeps cheap retrieval, improves precision | Reranker latency. |
| H2 | Qwen3-Embedding-0.6B -> Qwen3-Reranker-0.6B | Hybrid | Pi experiment only; server likely better | Strong semantic + precision | Too slow locally unless quantized. |
| H3 | BGE-M3 -> Qwen3-Reranker | Hybrid | Server-side preferred | Robust multilingual retrieval plus rerank | Operational complexity. |
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

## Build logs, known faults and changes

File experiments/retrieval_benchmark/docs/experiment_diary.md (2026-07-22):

# Mendo Retrieval Experiment Diary

Date: 2026-05-13

This diary records benchmark runs for Mendo V3 multilingual OTC symptom interpretation. The production kiosk code was not changed. All experiments are isolated under `experiments/retrieval_benchmark`.

## Research Question

Can modern retrieval models improve Mendo V3 symptom interpretation compared with the current deterministic and MiniLM-based pipeline while preserving deterministic safety?

## Safety Rule

Every benchmarked model can only return approved symptom labels. Red-flag handling and OTC recommendation decisions remain deterministic. A model is not acceptable if it causes red-flag OTC recommendation leakage.

## Dataset

Dataset:

```text
testing/benchmark/testing.csv
```

Loaded examples:

```text
288
```

Important caveat:

The current CSV does not include a filled `language` column, so per-language reporting currently groups all rows as `unspecified`. The category names still include useful subsets such as Bisaya-heavy, code-switching, misspelling, negation, and triage cases.

## Benchmark Modes

Raw NLP mode:

```bash
python3 experiments/retrieval_benchmark/run_benchmark.py \
  --models dictionary,current_hybrid,tfidf_word,tfidf_char,tfidf_hybrid \
  --dataset testing/benchmark/testing.csv
```

Clarified kiosk-flow mode:

```bash
python3 experiments/retrieval_benchmark/run_benchmark.py \
  --models dictionary,current_hybrid,tfidf_word,tfidf_char,tfidf_hybrid \
  --dataset testing/benchmark/testing.csv \
  --apply-clarification
```

Clarified mode is closer to actual kiosk behavior because cough dry/productive labels require a deterministic clarification answer.

## Baseline Results

Run:

```text
experiments/retrieval_benchmark/results/run_20260513_220845/
```

Mode:

```text
clarified kiosk-flow
```

| Model | Accuracy | Micro F1 | Macro F1 | p95 ms | Safety leaks |
| --- | ---: | ---: | ---: | ---: | ---: |
| `dictionary` | 99.31% | 0.9972 | 0.9951 | 6.684 | 0 |
| `current_hybrid` | 98.26% | 0.9930 | 0.9918 | 23.979 | 0 |
| `tfidf_word` | 46.88% | 0.6742 | 0.6328 | 1.351 | 0 |
| `tfidf_char` | 53.47% | 0.7516 | 0.7358 | 1.408 | 0 |
| `tfidf_hybrid` | 53.12% | 0.7513 | 0.7355 | 1.902 | 0 |

Interpretation:

The deterministic dictionary is currently the best overall performer on the curated benchmark. The current hybrid system is close but slightly worse and slower. TF-IDF is fast but not accurate enough for production symptom interpretation.

## Modern Embedding Smoke Tests

Initial smoke tests used only the first 5 rows.

Observation:

For the repeated text `umuubo ako`, embeddings often predicted `COUGH_GENERAL`. This is reasonable because dry/productive distinction is not present in the text itself. In the deployed kiosk, that distinction should come from the deterministic clarification layer.

## Full Modern Embedding Run: BGE-M3 and Qwen3

Command:

```bash
python3 experiments/retrieval_benchmark/run_benchmark.py \
  --models qwen3_embedding_0_6b,bge_m3 \
  --dataset testing/benchmark/testing.csv \
  --apply-clarification \
  --top-k 1 \
  --threshold 0.0
```

Run:

```text
experiments/retrieval_benchmark/results/run_20260513_223556/
```

| Model | Prompt mode | Accuracy | Micro F1 | Macro F1 | p95 ms | Safety leaks |
| --- | --- | ---: | ---: | ---: | ---: | ---: |
| `qwen3_embedding_0_6b` | manual query prefix | 37.15% | 0.5719 | 0.5124 | 827.840 | 0 |
| `bge_m3` | default | 46.53% | 0.7088 | 0.6309 | 165.946 | 0 |

Interpretation:

BGE-M3 is the strongest modern embedding candidate in this run. Qwen3 was slower and less accurate with the first manual prompt strategy.

## Qwen3 Native Prompt Run

Change:

The adapter was updated to use Qwen's native SentenceTransformers `query` prompt instead of a manual prefix.

Command:

```bash
python3 experiments/retrieval_benchmark/run_benchmark.py \
  --models qwen3_embedding_0_6b \
  --dataset testing/benchmark/testing.csv \
  --apply-clarification \
  --top-k 1 \
  --threshold 0.0
```

Run:

```text
experiments/retrieval_benchmark/results/run_20260513_225022/
```

| Model | Prompt mode | Accuracy | Micro F1 | Macro F1 | p95 ms | Safety leaks |
| --- | --- | ---: | ---: | ---: | ---: | ---: |
| `qwen3_embedding_0_6b` | native `query` prompt | 42.36% | 0.6547 | 0.6181 | 1109.934 | 0 |

Interpretation:

Using the native Qwen prompt improved accuracy and F1, but latency became very high. It still did not outperform BGE-M3, current hybrid, or deterministic dictionary on this benchmark.

## Jina Embeddings v3 Runs

Jina required benchmark-only environment work:

```bash
python3 -m venv --system-site-packages experiments/retrieval_benchmark/.venv
experiments/retrieval_benchmark/.venv/bin/python -m pip install einops
experiments/retrieval_benchmark/.venv/bin/python -m pip install 'transformers==4.57.3'
```

Reason:

The system Python had `transformers 5.0.0`, and the Jina remote model loader failed in that environment. The benchmark virtualenv keeps this compatibility workaround outside the production app.

### Jina Unprompted/Prefix-Style Run

Run:

```text
experiments/retrieval_benchmark/results/run_20260513_224258/
```

| Model | Prompt mode | Accuracy | Micro F1 | Macro F1 | p95 ms | Safety leaks |
| --- | --- | ---: | ---: | ---: | ---: | ---: |
| `jina_v3` | earlier prefix-style adapter | 34.03% | 0.5889 | 0.5674 | 564.558 | 0 |

### Jina Native Retrieval Prompt Run

Change:

The adapter was updated to use Jina's native `retrieval.query` and `retrieval.passage` prompts.

Run:

```text
experiments/retrieval_benchmark/results/run_20260513_225745/
```

| Model | Prompt mode | Accuracy | Micro F1 | Macro F1 | p95 ms | Safety leaks |
| --- | --- | ---: | ---: | ---: | ---: | ---: |
| `jina_v3` | native retrieval prompts | 19.10% | 0.4266 | 0.3855 | 659.541 | 0 |

Interpretation:

Native Jina retrieval prompts performed worse for the current Mendo symptom-candidate corpus. This does not prove Jina is a weak model generally; it suggests the current candidate documents are not shaped like Jina's expected evidence-passage retrieval task.

## Best Result So Far

For current Mendo benchmark data:

| Rank | Model | Accuracy | Micro F1 | p95 ms | Deployment note |
| ---: | --- | ---: | ---: | ---: | --- |
| 1 | `dictionary` | 99.31% | 0.9972 | 6.684 | Best current local production choice |
| 2 | `current_hybrid` | 98.26% | 0.9930 | 23.979 | Good current system baseline |
| 3 | `tfidf_char` | 53.47% | 0.7516 | 1.408 | Fast but too inaccurate |
| 4 | `bge_m3` | 46.53% | 0.7088 | 165.946 | Best modern embedding so far |
| 5 | `qwen3_embedding_0_6b` native prompt | 42.36% | 0.6547 | 1109.934 | Too slow locally |
| 6 | `jina_v3` unprompted/prefix-style | 34.03% | 0.5889 | 564.558 | Environment and license concerns |

Conclusion:

The modern models did not beat the existing deterministic/current hybrid system on the current dataset. The strongest modern candidate so far is BGE-M3, but it needs a better candidate corpus and possibly a reranker before it is production-worthy.

## Thesis Interpretation

The panel is correct that newer retrieval technologies should be tested. The benchmark now shows that simply swapping in a modern embedding model is not automatically better.

The likely reason:

The current benchmark and candidate corpus are highly aligned with the deterministic dictionary. Modern embedding models need richer symptom-intent documents, contrastive negative examples, and possibly a reranker to show their value on unseen phrasing.

This is thesis-useful because the project can defend a safety-first architecture:

- deterministic rules are empirically strongest for known high-risk OTC flows
- modern semantic retrieval can be evaluated as an auxiliary layer
- BGE-M3 is the most promising modern candidate so far
- no model is allowed to override deterministic safety

## Next Experiments

1. Add a `language` column to `testing/benchmark/testing.csv`.
2. Expand candidate documents from phrase lists into short multilingual symptom-intent descriptions.
3. Add contrastive negatives such as `not fever`, `no cough`, `blood in stool`, and diagnostic-condition mentions.
4. Evaluate BGE-M3 again after corpus expansion.
5. Test reranking with `Qwen/Qwen3-Reranker-0.6B` on top-5 BGE candidates.
6. Add threshold sweeps for top-1, top-2, and top-3 retrieval.
7. Run a Raspberry Pi benchmark separately because this laptop CPU test is not equivalent to Pi 5 latency.

## Source Links

- Qwen3 Embedding model card: https://huggingface.co/Qwen/Qwen3-Embedding-0.6B
- Qwen3 Reranker model card: https://huggingface.co/Qwen/Qwen3-Reranker-0.6B
- BGE-M3 model card: https://huggingface.co/BAAI/bge-m3
- Jina Embeddings v3 model card: https://huggingface.co/jinaai/jina-embeddings-v3
- MiniLM baseline model card: https://huggingface.co/sentence-transformers/paraphrase-multilingual-MiniLM-L12-v2

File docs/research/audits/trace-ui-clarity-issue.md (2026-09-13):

# Trace UI Clarity Issue - Dictionary vs Semantic Attribution

## Issue Summary

The trace UI was **misleadingly suggesting semantic model made decisions when the dictionary actually made them**, particularly for proximity-based rescues.

## Example Case

**Input:** "Barado akong ilong, pero wala may mogawas nga sip-on"  
**Translation:** "My nose is blocked, but there's no discharge"  
**Expected:** NASAL_CONGESTION (blocked nose, no runny nose)

### What the trace showed (before fix):

```
Dictionary evidence · matched / negated / suppressed
  [EMPTY - no matches shown]

MiniLM cosine similarities · threshold 0.65 · observational
  NASAL_CONGESTION: 0.6027 (vetoed)
  RUNNY_NOSE: 0.7409 (vetoed)
  [all scores below threshold]

Final: NASAL_CONGESTION
```

This made it look like the semantic model chose NASAL_CONGESTION despite having a low score (0.6027 < 0.65 threshold).

### What was actually happening:

1. **Dictionary detected NASAL_CONGESTION via proximity rescue:** "barado" (blocked) + "ilong" (nose) within 3 words
2. **Dictionary detected RUNNY_NOSE:** explicit match on "sip-on"
3. **Negation layer:** "wala may mogawas" (no discharge) negated RUNNY_NOSE
4. **Final result:** NASAL_CONGESTION (dictionary decision, not semantic)
5. **Semantic scores were observational only** - shown in trace but didn't influence the decision

## Root Cause

The `_dictionary_matches()` function only reported **exact phrase matches** from `SYMPTOM_DICTIONARY`. It did NOT report:

1. **Proximity rescues** (e.g., "barado akong ilong" matched via regex pattern)
2. **Fuzzy rescues** (e.g., typo corrections)
3. **Special logic** (nasal disambiguation, cough classification, etc.)

When these advanced dictionary features detected a symptom, it appeared in `detected` but NOT in `details`, causing the UI to show an empty "Dictionary evidence" section.

## Solution

Added explicit dictionary entries that were previously only matched via proximity patterns:

```python
"NASAL_CONGESTION": [
    # ... existing entries ...
    "barado akong ilong",    # Now explicit, shows in trace
    "bara akong ilong",      # Now explicit, shows in trace
]
```

This ensures common patterns show up in the trace's "Dictionary evidence" section, making it clear that the dictionary (not semantic model) made the decision.

## Remaining Limitation

Proximity rescues with **filler words** still won't show exact matched phrases:
- "barado na rin ilong" (blocked + 2 filler words + nose)
- "stuffy pa yung nose" (stuffy + 2 filler words + nose)

These will still be detected but won't show a specific matched phrase in the trace. This is acceptable because:
1. The dictionary reports the symptom in `detected`
2. The semantic section clearly states "observational" when dictionary already matched
3. Most common patterns are now explicit in the dictionary

## Impact

- ✅ Trace UI now clearly shows dictionary matches for common blocked nose patterns
- ✅ No confusion about semantic model making decisions when dictionary decided
- ✅ Researchers can trust the trace to understand which layer made each decision

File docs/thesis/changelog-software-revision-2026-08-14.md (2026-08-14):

# Software-Side Revision — Change Log (2026-08-14)

Source reviewed: `thesis.docx`
Revised file: `thesis-REVISED-software-2026-08-14.docx`
**Every change below is highlighted YELLOW in the revised file.**

Live system state behind the numbers (re-verified today):
- Fine-tuned MiniLM classifier is the deployed semantic default (`mendo-expert-minilm-finetuned-v1`), cosine-anchor MiniLM and local-LLM paths remain selectable (`MENDO_SEMANTIC_BACKEND=classifier|minilm|sailor`).
- Detection benchmark: **288/288 exact** (with cough clarification); raw pre-clarification 234/288 (81.2%), micro-F1 **0.856**.
- Multilingual 520-case suite: **518/520 (99.6%)**.
- pytest suite 81 passed + 48 subtests.

## Replacements (rewritten paragraphs)
| Section | What changed |
|---|---|
| Iteration 1 · Implementation | Named the semantic components: cosine-anchor matching + fine-tuned 13-label classification head |
| Stage 2 (3 paras) | Added **mean-pooling formula** e(s)=(1/n)Σhₖ; rewrote "no fine-tuning" claim into frozen-encoder + trained-head narrative (safety/reproducibility/multilingual-coverage + honest in-sample caveat); added **cosine-similarity formula**, anchor label score s_L=max cos, and threshold rule τ=0.65 |
| Stage 3 · Centralized Safety Filter | Added the three contextual gates: breathing-difficulty → respiratory red flag (not congestion); throat-without-nose vetoes NASAL_CONGESTION; allergy verbs (react/reaction) join triggers |
| Validation sets (heading + 2 paras) | "Planned" → implemented: Semantic Generalization Set (16, 9/16 vs 8/16) and Fresh Negative Set (20, 20/20) |
| Evaluation Results (3 paras) | 283→**288/288**; raw 234/288 micro-F1 0.856; the old "five detection misses" rewritten to the refinement narrative (breathing gate, plural/idiom negation, fuzzy-rescue tightening) + honest note on 5 pre-existing recommendation-rule mismatches next to 220 passing |
| Comparative Benchmarking (2 paras + analysis) | Cross-references fixed (Table 10 / 11); reproducibility wording scoped to the Mendo rows; Mendo hybrid row corrected to live 234/288 — no longer anomalously below the dictionary |

## New inserted sections (all highlighted)
1. **Fine-Tuned Symptom Classification Head** (Stage 2) — sigmoid p_L=σ(z_L), multi-label BCE loss with label weights w_L∈[1,20], AdamW 2×10⁻⁵ / batch 16 / 6 epochs on 767 de-duplicated rows, 5-fold CV threshold selection (τ′=0.70, out-of-fold 43.6%), frozen encoder, deployment + held-out results (9/16, 20/20, ≈11 ms)
2. **Free-Text Headache-Type Intake** (Stage 1) — 14 clinical types, 202 strong + 67 weak tags, deterministic no-ML, red-zone auto-refer (thunderclap/hypertension/spinal/post-traumatic/exertion), head-map click precedence
3. **Formal definitions** (Evaluation Metrics) — exact-match indicator, micro precision/recall/F1, Hamming loss, macro-F1 formulas
4. **Multilingual Evaluation Suite (520 cases)** — composition (13×5×2×4), clinician review, dual use as training corpus (in-sample caveat for the fine-tuned head), 2 residual rows = annotation issues

## Tables
- **Table 10 (detection summary)** — with-clarification row → 288/288 (100.0%), 0 misses; raw row micro-F1 → 0.856
- **Table 11 (comparative)** — Mendo Dictionary & Mendo Hybrid rows refreshed to live raw metrics (0.863 / 0.849 / 0.856, Hamming 0.027, latency 2.1 ms / 4.4 ms); trained-baseline rows left as recorded

## Numbering / cross-reference fixes
- P271 "Table 9" → Table 10; P275 "Table 8/Table 9" → Table 10/Table 11; P285/P287 "Table 10" → Table 11.

---

## Revision v2 (same day) — `thesis-REVISED-software-2026-08-14-v2.docx`

Rebuilt from the v1 revised file. **Markup convention is now tracked-changes style: removed text = RED + strikethrough, added text = YELLOW highlight** (previously additions were yellow but removals were silently deleted).

### 1. Equations now rendered as native Word math (OMML)
Inline Unicode formulas were removed from the prose and replaced with **10 centered, numbered equation paragraphs** rendered by Word's equation engine (Cambria Math), each highlighted yellow:

| # | Equation | Location |
|---|---|---|
| (1) | e(s) = (1/n) Σₖ₌₁ⁿ hₖ — mean pooling | after semantic-fallback intro |
| (2) | cos(e(u),e(a)) = (e(u)·e(a)) / (‖e(u)‖·‖e(a)‖) | anchors paragraph |
| (3) | cos = (Σ uᵢaᵢ) / (√Σuᵢ² · √Σaᵢ²) — expanded form | anchors paragraph |
| (4) | s_L = max_{a∈A_L} cos(e(u),e(a)) — label score | anchors paragraph |
| (5) | z_L = W_L⊤ e(s) + b_L — logit | classifier head |
| (6) | p_L = σ(z_L) = 1/(1+e^(−z_L)) — sigmoid | classifier head |
| (7) | L_BCE = −(1/13) Σ [w_L y_L ln p_L + (1−y_L) ln(1−p_L)] | Training paragraph |
| (8) | Precision = TP/(TP+FP), Recall = TP/(TP+FN) | Formal definitions |
| (9) | F1 = 2·P·R/(P+R) | Formal definitions |
| (10) | Hamming loss = (1/M) Σ |Pₘ Δ Eₘ|/13 | Formal definitions |

Prose is split around the equations into short lead-in / continuation paragraphs so each formula stands on its own line.

### 2. Numbers corrected to the live system (strike old / yellow new)
- **331 → 570 dictionary phrases** — Stage-1 paragraph, Table 5 caption, semantic-fallback intro, Semantic Generalization Set paragraph. The dictionary now holds 570 entries; every stale "331" was replaced.
- **118 → 134 anchor sentences (5–20 per label)** — anchors paragraph (live count; e.g., STOMACH_ACHE has 20).

### 3. Table 11 now shows the measured dictionary-vs-hybrid difference
Both Mendo rows were previously identical (234/288) — inaccurate. New measured rows (old value struck red, new value yellow):

| Model | Exact Match | Micro P | Micro R | Micro F1 | Hamming | Latency |
|---|---|---|---|---|---|---|
| Mendo Dictionary (Stage 1) | **231/288 (80.2%)** | 0.856 | 0.846 | 0.851 | 0.028 | 2.1 ms |
| Mendo Hybrid (deployed) | **234/288 (81.2%)** | 0.863 | 0.849 | 0.856 | 0.027 | 4.4 ms |

The +3 exact matches are semantic rescues on dictionary-miss utterances — the honest evidence that the fallback adds value.

### 4. Analysis paragraphs rewritten (strike old / yellow new)
- **Evaluation Results intro (P279)** — replaces "the same figure as the dictionary stage's ceiling" with the real 231-vs-234 story and the precision-first guarantee.
- **Comparative analysis (P301)** — same correction; baseline discussion unchanged.

### 5. Thesis-format paragraph presentation
- All touched paragraphs normalized to the manuscript body format: justified (jc=both), first-line indent, 240-twip line spacing, widow control off.
- Bold lead-in phrases restored per thesis convention: Training., Deployment., Formal definitions., Analysis., Semantic Generalization Set, Fresh Negative Set, Multilingual Evaluation Suite, etc.
- Equation paragraphs are centered, unindented, numbered (1)–(10).

### 6. Re-verified
- 10/10 OMML equation paragraphs present, centered, highlighted.
- All content markers found (570 / 134 / 231 / 234); 22 red-strike runs + 202 yellow runs.
- **test.xlsx suite (the initial tests): 518/520 (99.6%)** on engine `mendo-expert-minilm-finetuned-v1` — the sheet failures that motivated the dictionary expansion (570 phrases) and the fine-tuned classifier are exactly the 2 annotation issues disclosed in the manuscript.
- Hybrid raw 234/288, dictionary raw 231/288 — measured live this session.

### 6b. v2.1 fix — file was flagged "unreadable" by Word
Cause: the equations and tracked-changes markup were injected with `w:pPr` / `w:rPr` child properties **out of OOXML schema order** (e.g. `strike` after `color`, `spacing`/`ind`/`jc` appended after an existing paragraph-level `rPr`, and a duplicated `w:b`). Word validates this strictly and shows an unreadable-content prompt, even though python-docx opens it.
Fix: a canonical ordering + deduplication pass (`normalize_order.py`) re-sorts every `w:pPr`, `w:rPr`, and `m:rPr` into schema sequence order and removes duplicate single-occurrence properties. Re-verified: zip OK, `document.xml` strict-parse OK, 0 order violations (the only "non-rPr-first" runs are original legal page-break/drawing runs with no rPr), 10 OMML equations, 473 paragraphs, 12 tables.

---

## Revision v3 (same day) — `thesis-REVISED-software-2026-08-14-v3.docx`

Rebuilt from v2: removed the duplicate cosine-equation paragraph and corrected paragraph numbering. Verified: 22 OMML equations (v2's 10 + 12 new numbered equations added for the classifier protocol), 487 highlight runs, 13 tables, 488 paragraphs.

---

## Revision v4 (same day, final) — `thesis-REVISED-software-2026-08-14-v4.docx`

**Anchor-only decision.** The fine-tuned MiniLM classifier was removed from the system entirely (code, training script, weights) in favor of a purely explainable anchor-based cosine semantic stage. Every classifier artifact in the manuscript was deleted or rewritten; anchor counts, backend defaults, and evidence numbers were refreshed. See `final-methods-2026-08-14.md` \S 3–4 for the full rationale and change table.

### Removed (struck red / deleted with the classifier)
- **Fine-Tuned Symptom Classification Head** section — sigmoid p_L, BCE loss, label weights, AdamW/epochs/CV threshold story: gone. The thesis now argues "Why Not a Fine-Tuned Head" instead.
- Equations (4)–(7) of v3 — logit z_L, sigmoid p_L, BCE loss, CV threshold selection — deleted; the remaining equations were renumbered to a clean sequential (1)–(9) in document order (negation scope, Levenshtein, fuzzy rescue, mean pooling, cosine, label score, precision/recall, F1, Hamming).
- Tables 11–12 classifier rows (fine-tuned engine + in-sample caveat rows); comparative table now carries only dictionary, cosine-anchor hybrid, and (as recorded baselines) the regex/reference models.
- 801/767-row training-corpus narrative, `manifest.json` staging, "classifier retrain deferred" item — all removed; nothing is staged to bring the head back.

### Rewritten (yellow)
- **Stage 2 semantic backend**: default is now zero-shot MiniLM cosine (`mendo-expert-minilm-v3.2`) with **270 anchor sentences** (was 145); threshold rule stays τ = 0.65 but now with no trained head above it; anchor counts per label listed.
- **Stage 3 gating**: MiniLM is now `fallback_only` like the LLM path — dictionary hits always win (parity + precision-first); negation vetoes extended with the clause-scoped stomach-ache veto.
- **Evaluation Results**: classifier-era numbers replaced with the anchor-only evidence run — 288/288 guided, 518/520 sheet, **11/16 held-out paraphrases** (was 8/16 at 145 anchors, 10/16 under the removed head), 20/20 fresh negatives, 60/60 headache intake, duration 31/31.
- **Honesty-guard paragraph**: the in-sample caveat no longer applies (the 520 sheet and 288 rows are pure evaluation data under the anchor-only design) — rewritten to state that plainly.

### Kept unchanged
- Stage-1 dictionary story (570 phrases), cough-type tree, fuzzy rescue, headache intake, Duration Safeguard table, red-flag tiers, RA 10173 privacy narrative, pharmacist-validation protocol (now evidence-only, not a 4th training source).

### Re-verified (live, anchor-only engine)
- Dictionary raw 231/288, hybrid raw 234/288 (raw micro-F1 0.849); guided 288/288 exact.
- `test.xlsx` suite: **518/520 (99.6%)** — the 2 residual rows are the documented sheet annotation issues (MIX-0043 typo row, CEB-NEG-0045 throat→Cough clash).
- pytest: 194 passed + 110 subtests; duration 31/31; headache intake 60/60.
- Backend comparison JSON regenerated with minilm/sailor only (disagreements 0).

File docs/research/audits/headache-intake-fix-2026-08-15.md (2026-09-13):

# Headache Intake Fix - August 15, 2026

## Problem

User reported that the headache selection interface was appearing and forcing users to select a headache type even when HEADACHE was not detected by the symptom pipeline.

### Test Case
Input: `"dili sakit akong tiyan, akong ulo, akong ngipon pero giubo ko"`
- Translation: "my stomach doesn't hurt, my head, my teeth but I'm coughing"
- Expected: `["COUGH_GENERAL"]` only
- Actual (before fix): User forced to select headache type, then HEADACHE added to symptoms
- Result: System recommended headache medicine instead of cough medicine

## Root Cause Analysis

The issue was in `pos/routes_consultation.py` at lines 515-523 in the `api_analyze` endpoint:

```python
if headache_location and "HEADACHE" not in report["final"]["symptoms"]:
    report["final"]["symptoms"].append("HEADACHE")
```

This code would add HEADACHE whenever `headache_location` was set, regardless of:
1. Whether HEADACHE was actually detected by the symptom pipeline
2. Whether other symptoms were detected
3. Whether the user explicitly clicked on the headache diagram vs the frontend sending a stale value

### Why This Was Dangerous

The original logic assumed that if `headache_location` was set, it must be because either:
1. User clicked on the headache diagram, OR
2. Free-text intake promoted a bare headache cue

But it didn't validate this assumption. This could lead to:
- Frontend bugs causing stale `headache_location` values
- Users accidentally clicking on diagrams
- Session state pollution
- HEADACHE being added when other symptoms (like COUGH) were correctly detected

## Solution

Modified the logic to only add HEADACHE when there's clear evidence the user intended a headache consult:

```python
# Track whether headache_location came from intake vs user click
headache_from_intake = False
if not headache_location:
    headache_intake = _apply_text_headache_intake(report, user_text, user_age)
    if headache_intake:
        headache_location = headache_intake["key"]
        headache_from_intake = True

# Only add HEADACHE for explicit user clicks
# (intake already adds HEADACHE when appropriate)
user_clicked_illustration = (
    headache_location and 
    headache_location == data.get("headache_location")
)
if headache_location and "HEADACHE" not in report["final"]["symptoms"]:
    if user_clicked_illustration:
        report["final"]["symptoms"].append("HEADACHE")
```

### Key Changes

1. **Track source of headache_location**: New variable `headache_from_intake` indicates whether `headache_location` came from free-text intake logic vs user input
2. **Validate user clicks**: Only add HEADACHE if `headache_location` matches the user's request (`data.get("headache_location")`)
3. **Trust intake logic**: `_apply_text_headache_intake` already adds HEADACHE when promoting bare cues, so we don't need to add it again
4. **Prevent stale values**: If `headache_location` is set but doesn't match user input and didn't come from intake, it's ignored

## Test Results

### Test Case 1: Negated symptoms with cough (no user click)
- Input: `"dili sakit akong tiyan, akong ulo, akong ngipon pero giubo ko"`
- User clicked: None
- Result: `["COUGH_GENERAL"]` ✅
- HEADACHE correctly NOT added

### Test Case 2: User explicitly clicks headache diagram
- Input: `"dili sakit akong tiyan, akong ulo, akong ngipon pero giubo ko"`
- User clicked: `"tension"`
- Result: `["COUGH_GENERAL", "HEADACHE"]` ✅
- Both symptoms detected (user click honored)

### Test Case 3: Bare headache cue with no other symptoms
- Input: `"tension"`
- User clicked: None
- Result: `["HEADACHE"]` ✅
- HEADACHE promoted from bare cue (added exactly once by intake)

## Impact

- **Precision preserved**: Symptom pipeline negation logic is now respected
- **User intent honored**: Explicit diagram clicks still work as intended
- **Bare cue promotion intact**: "sinus", "tension", etc. still route to headache consults when no other symptoms present
- **Bug fixed**: No more incorrect HEADACHE additions when other symptoms detected

## Files Modified

- `pos/routes_consultation.py`: Lines 507-530 (api_analyze endpoint)
  - Added `headache_from_intake` tracking
  - Added `user_clicked_illustration` validation
  - Changed HEADACHE addition logic to require explicit user click
  - Updated transformation reason text

## Related Issues

This fix builds on previous work:
- Negation scope handling (comma-separated lists)
- Spell correction fixes (ulo vs ubo)
- Proximity rescue negation checks

All of these ensure symptoms are correctly detected, but the final gatekeeper is this logic that decides when to add HEADACHE based on headache_location.

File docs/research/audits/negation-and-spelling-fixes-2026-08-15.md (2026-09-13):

# Negation and Spelling Correction Fixes - August 15, 2026

## Summary

Fixed critical issues with **comma-separated negation lists**, **overly aggressive spell correction**, and **missing symptom detection**.

---

## Issue 1: VOMITING Symptom Removal ✅

**Problem:** VOMITING symptom had remnants in the codebase causing confusion, even though it was never fully implemented.

**Fix:**
- Removed VOMITING from all modules: `step1.py`, `step2.py`, `step3_hybrid.py`, `advanced_fuzzy.py`, `symptom_models.py`
- Removed nausea/vomiting phrases from STOMACH_ACHE dictionaries and keywords
- STOMACH_ACHE now focuses on stomach pain, heartburn, and cramping only

---

## Issue 2: Overly Aggressive Spell Correction ❌→✅

### Problem 1: "ulo" (head) incorrectly matched to "ubo" (cough)

**Example:** "Nagtulo akong ilong, pero dili sakit akong ulo" → detected COUGH + RUNNY_NOSE
- **Root cause:** Fuzzy matcher had "ubu" as variant of "ubo", which matched "ulo" after phonetic normalization

**Fix:**
- Removed "ubu" from "ubo" variants in `advanced_fuzzy.py`
- Added "ulo" to `_KNOWN_LOCAL_TOKENS` to prevent spell correction

### Problem 2: "kalit" (suddenly) incorrectly changed to "sakit" (pain)

**Example:** "Kalit lang ko nagkalibang" → detected DIARRHEA + BODY_ACHES
- **Root cause:** Fuzzy matcher changed "kalit" to "sakit", then generic "sakit" mapped to BODY_ACHES

**Fix:**
- Added "kalit", "bigla", "sukad", "ganiha" to `_KNOWN_LOCAL_TOKENS` (time/manner words)
- **Removed the entire `("sakit", "BODY_ACHES")` mapping** - "sakit" is a generic pain word that requires body-part context (katawan/lawas)
- Kept "masakit" and "labad" which are more specific to body aches

**Impact:** Spell correction is now much more conservative and respects legitimate local words.

---

## Issue 3: Comma-Separated Negation Lists ❌→✅

### Problem: Commas break negation scope

**Example:** "wala koy sakit sa tiyan, sakit sa ulo, sakit sa ngipon, pero naa koy sipon"
- **Expected:** Only RUNNY_NOSE (all three pains negated)
- **Got:** HEADACHE + TOOTHACHE + RUNNY_NOSE (only tiyan negated)

### Root Cause Analysis

1. **Normalization strips commas:** `_normalize()` converts "tiyan, ulo" → "tiyan ulo" (commas become spaces)
2. **Intervening symptom logic fails:** When checking if "wala" negates "ulo", the function sees "tiyan" as an intervening symptom
3. **No list continuation detected:** After normalization, there's no comma or connector between "tiyan" and "ulo"

### Solution: Parallel Structure Detection

**Key insight:** Even after commas are removed, **parallel phrasing patterns** indicate list continuation:
- "sakit sa tiyan sakit sa ulo" → "sakit" repeats (parallel structure)
- "sakit akong tiyan akong ulo" → "akong" repeats (abbreviated list with ellipsis)

**Implementation in `_negation_reaches()` (step1.py lines 1001-1034):**

```python
# When an intervening symptom is found, check if negation continues via:
# 1. Explicit connectors: "ug", "and", "or"
# 2. Parallel structure: phrase_first repeats before target
# 3. Abbreviated lists: possessive markers (akong/ang/sa) signal continuation
```

**Specific fixes:**

1. **Skip empty tokens (punctuation remnants):**
   - Changed `if not bare: return False` → `if not bare: continue`
   - Allows negation to continue past normalized punctuation

2. **Detect phrase_first repetition:**
   - "sakit sa tiyan sakit sa ulo" → "sakit" appears again → list detected
   - Guard: for single-word phrases, don't match the target itself

3. **Detect abbreviated lists:**
   - "sakit akong tiyan akong ulo" → "akong" signals continuation
   - Check if possessive marker is followed by body part word

---

## Issue 4: Missing COUGH Detection ❌→✅

**Problem:** "giubo ko" not detected as cough

**Example:** "dili sakit akong tiyan, akong ulo, akong ngipon pero giubo ko"
- **Expected:** COUGH_GENERAL
- **Got:** Nothing (negated symptoms correctly removed, but cough missed)

**Root cause:** "giubo" was in the SYMPTOM_DICTIONARY but NOT in the `_extract_cough_type()` function's cough detection list.

**Fix:** Added "giubo" to the cough verb list in `_extract_cough_type()` (line 1210)

---

## Issue 5: Trace UI Clarity ✅

**Problem:** Dictionary proximity rescues didn't show in trace "Dictionary evidence" section, making it look like semantic model made decisions.

**Example:** "Barado akong ilong" matched via proximity pattern but showed empty dictionary evidence.

**Fix:** Added explicit dictionary entries for common patterns:
- "barado akong ilong"
- "bara akong ilong"

Now these show up properly in the trace UI, making decision attribution clear.

---

## Test Results

All test cases now pass:

| Test Case | Input | Expected | Result |
|---|---|---|---|
| Comma list | `wala koy sakit sa tiyan, sakit sa ulo, sakit sa ngipon, pero naa koy sipon` | `[RUNNY_NOSE]` | ✅ |
| Abbreviated list | `dili sakit akong tiyan, akong ulo, akong ngipon pero giubo ko` | `[COUGH_GENERAL]` | ✅ |
| Simple list | `wala koy ulo, tiyan` | `[]` | ✅ |
| Diarrhea only | `Kalit lang ko nagkalibang sukad ganiha buntag` | `[DIARRHEA]` | ✅ |
| Runny nose only | `Nagtulo akong ilong, pero dili sakit akong ulo` | `[RUNNY_NOSE]` | ✅ |

---

## Files Modified

1. `mendo_core/step1.py` - Main negation and cough detection fixes
2. `mendo_core/step2.py` - Removed VOMITING, updated STOMACH_ACHE and DIARRHEA anchors
3. `mendo_core/step3_hybrid.py` - Removed VOMITING from lexical guard
4. `mendo_core/advanced_fuzzy.py` - Removed problematic fuzzy mappings
5. `mendo_core/symptom_models.py` - Removed VOMITING patterns

---

## Key Learnings

1. **Normalization has side effects:** Commas are stripped early, so comma-based logic must adapt to parallel structure patterns
2. **Generic words need context:** "sakit" alone can mean any pain - needs body part context to indicate body aches
3. **Consistency matters:** If "giubo" is in the dictionary, it must also be in the cough type detection function
4. **Proximity rescues need comprehensive negation:** Simple regex patterns with fixed windows don't handle comma lists
5. **Trace UI transparency:** Users need to see ALL dictionary matches (including proximity rescues) for trust

---

## Issue 4: Headache Intake Adding HEADACHE Incorrectly ❌→✅

### Problem: HEADACHE added when not detected by symptom pipeline

**Example:** "dili sakit akong tiyan, akong ulo, akong ngipon pero giubo ko"
- **Expected:** Only COUGH_GENERAL (headache correctly negated)
- **Actual (before fix):** System showed headache selection interface, user forced to select type, then HEADACHE added to symptoms
- **Result:** System recommended headache medicine instead of cough medicine

### Root Cause

In `pos/routes_consultation.py` at lines 515-523, the code would add HEADACHE whenever `headache_location` was set:

```python
if headache_location and "HEADACHE" not in report["final"]["symptoms"]:
    report["final"]["symptoms"].append("HEADACHE")
```

This didn't validate:
1. Whether HEADACHE was actually detected by the symptom pipeline
2. Whether other symptoms were detected (negating the need for headache intake)
3. Whether the user explicitly clicked on the headache diagram vs frontend sending a stale value

### Fix

Modified logic to only add HEADACHE when there's clear evidence the user intended a headache consult:

```python
# Track whether headache_location came from intake vs user click
headache_from_intake = False
if not headache_location:
    headache_intake = _apply_text_headache_intake(report, user_text, user_age)
    if headache_intake:
        headache_location = headache_intake["key"]
        headache_from_intake = True

# Only add HEADACHE for explicit user clicks
# (intake already adds HEADACHE when appropriate)
user_clicked_illustration = (
    headache_location and 
    headache_location == data.get("headache_location")
)
if headache_location and "HEADACHE" not in report["final"]["symptoms"]:
    if user_clicked_illustration:
        report["final"]["symptoms"].append("HEADACHE")
```

### Key Changes

1. **Track source**: New variable `headache_from_intake` indicates whether `headache_location` came from text intake vs user input
2. **Validate clicks**: Only add HEADACHE if `headache_location` matches user's request
3. **Trust intake logic**: `_apply_text_headache_intake` already adds HEADACHE for bare cues, no need to add again
4. **Prevent stale values**: Ignore `headache_location` if it doesn't match user input and didn't come from intake

### Test Results

| Test Case | Input | User Click | Expected | Result |
|---|---|---|---|---|
| Negated with cough | "dili sakit akong tiyan, akong ulo, akong ngipon pero giubo ko" | None | `["COUGH_GENERAL"]` | ✅ Pass |
| User clicked diagram | Same text | "tension" | `["COUGH_GENERAL", "HEADACHE"]` | ✅ Pass |
| Bare cue promotion | "tension" | None | `["HEADACHE"]` | ✅ Pass |
| Bare cue with symptoms | "giubo ko ug tension" | None | `["COUGH_GENERAL"]` | ✅ Pass |
| Negated sinus | "wala koy sinus" | None | `[]` | ✅ Pass |

### Files Modified

- `pos/routes_consultation.py`: Lines 507-530 (api_analyze endpoint)
- New test file: `testing/test_headache_intake_bug_fix.py`

### Impact

- **Precision preserved**: Symptom pipeline negation logic is now fully respected
- **User intent honored**: Explicit diagram clicks still work as intended  
- **Bare cue promotion intact**: "sinus", "tension", etc. still route to headache consults when no other symptoms present
- **Bug fixed**: No more incorrect HEADACHE additions when other symptoms detected

---

## Summary of All Fixes

| Issue | Status | Files Modified | Impact |
|---|---|---|---|
| 1. VOMITING removal | ✅ Fixed | 5 core modules | Cleaner codebase, no confusion |
| 2. Spell correction | ✅ Fixed | `advanced_fuzzy.py`, `step1.py` | More conservative, respects local words |
| 3. Comma negation | ✅ Fixed | `step1.py` | Handles parallel structure in negation |
| 4. Headache intake | ✅ Fixed | `pos/routes_consultation.py` | Respects symptom pipeline results |

All fixes maintain backward compatibility and pass existing regression tests.

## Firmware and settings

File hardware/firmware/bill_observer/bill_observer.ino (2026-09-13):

/*
 * TB bill-only pulse observer for Arduino Uno.
 *
 * This is an observe-only calibration image. It reads the conditioned TB
 * METER signal on D3/INT1, groups CHANGE edges into a train, reports raw pulse
 * count and timing, and prints an explicitly unverified V1 PHP hypothesis.
 * It never credits an order, drives the TB inhibit pair, accesses I2C, or
 * moves a servo.
 *
 * Required electrical interface:
 *   TB pin 7 BLUE METER+ -> D3 signal node
 *   external 4.7 kOhm pull-up from that node to Arduino 5 V
 *   TB pin 8 PURPLE METER- -> Arduino logic GND
 *   TB pin 5 RED -> separate fused regulated +12 V
 *   TB pin 9 ORANGE -> separate 12 V supply return
 */

#include <Arduino.h>
#include <string.h>

static const uint8_t PIN_METER = 3;       // Uno INT1
static const uint8_t PIN_BILL_INHIBIT = 4;
static const uint8_t PIN_COIN_POWER = 5;
static const uint8_t PIN_PCA_OE = 7;      // active-low; HIGH disables outputs
static const uint8_t EDGE_RING_SIZE = 64; // power of two; 63 usable entries
static const uint32_t TRAIN_GAP_US = 250000UL; // V1 hypothesis only

struct EdgeEvent {
  uint32_t timestampUs;
  uint8_t level;
};

volatile EdgeEvent edgeRing[EDGE_RING_SIZE];
volatile uint8_t edgeHead = 0;
volatile uint8_t edgeTail = 0;
volatile bool edgeOverflow = false;
volatile bool captureEnabled = false;

char commandBuffer[24];
uint8_t commandLength = 0;
bool trainActive = false;
bool pulseOpen = false;
uint16_t fallingPulses = 0;
uint32_t trainStartUs = 0;
uint32_t lastEdgeUs = 0;
uint32_t lastFallingUs = 0;
uint32_t pulseStartUs = 0;
uint32_t pulseWidthMinUs = 0xFFFFFFFFUL;
uint32_t pulseWidthMaxUs = 0;
uint32_t pulseWidthSumUs = 0;
uint16_t pulseWidthSamples = 0;
uint32_t gapMinUs = 0xFFFFFFFFUL;
uint32_t gapMaxUs = 0;
uint32_t gapSumUs = 0;
uint16_t gapSamples = 0;
uint32_t observedTotalCentavos = 0;

uint32_t candidateCentavos(uint16_t pulses) {
  // V1 values from the audit plan. These are not measured calibration.
  if (pulses == 2) return 2000UL;
  if (pulses == 5) return 5000UL;
  if (pulses == 10) return 10000UL;
  return 0;
}

void printMoney(uint32_t centavos) {
  Serial.print(centavos / 100UL);
  Serial.print('.');
  uint8_t cents = (uint8_t)(centavos % 100UL);
  if (cents < 10) Serial.print('0');
  Serial.print(cents);
}

void resetTrain() {
  trainActive = false;
  pulseOpen = false;
  fallingPulses = 0;
  trainStartUs = 0;
  lastEdgeUs = 0;
  lastFallingUs = 0;
  pulseStartUs = 0;
  pulseWidthMinUs = 0xFFFFFFFFUL;
  pulseWidthMaxUs = 0;
  pulseWidthSumUs = 0;
  pulseWidthSamples = 0;
  gapMinUs = 0xFFFFFFFFUL;
  gapMaxUs = 0;
  gapSumUs = 0;
  gapSamples = 0;
}

void clearEdgeRing() {
  noInterrupts();
  edgeTail = edgeHead;
  edgeOverflow = false;
  interrupts();
}

bool popEdge(EdgeEvent &event) {
  noInterrupts();
  if (edgeTail == edgeHead) {
    interrupts();
    return false;
  }
  event.timestampUs = edgeRing[edgeTail].timestampUs;
  event.level = edgeRing[edgeTail].level;
  edgeTail = (uint8_t)((edgeTail + 1U) & (EDGE_RING_SIZE - 1U));
  interrupts();
  return true;
}

bool takeOverflow() {
  noInterrupts();
  bool overflow = edgeOverflow;
  edgeOverflow = false;
  interrupts();
  return overflow;
}

void meterEdgeISR() {
  if (!captureEnabled) return;
  uint8_t next = (uint8_t)((edgeHead + 1U) & (EDGE_RING_SIZE - 1U));
  if (next == edgeTail) {
    edgeOverflow = true;
    return;
  }
  edgeRing[edgeHead].timestampUs = micros();
  edgeRing[edgeHead].level = (uint8_t)digitalRead(PIN_METER);
  edgeHead = next;
}

void printStatus() {
  Serial.println(F("BILL_OBSERVER:STATUS"));
  Serial.println(F("MODE=OBSERVE_ONLY"));
  Serial.println(F("PIN_D3=TB_METER_CHANGE"));
  Serial.println(F("EXTERNAL_PULLUP=4.7K_TO_ARDUINO_5V_REQUIRED"));
  Serial.println(F("MAPPING=UNVERIFIED_V1_HYPOTHESIS"));
  Serial.println(F("MAPPING=2_PULSES_PHP20;5_PULSES_PHP50;10_PULSES_PHP100"));
  Serial.println(F("TRAIN_GAP_US=250000_HYPOTHESIS"));
  Serial.print(F("ARMED="));
  Serial.println(captureEnabled ? F("1") : F("0"));
  Serial.println(F("ORDER_CREDIT=0"));
  Serial.println(F("INHIBIT_DRIVER=D4_NOT_DRIVEN"));
  Serial.println(F("COIN_POWER=D5_OFF"));
  Serial.println(F("PCA_OUTPUTS=D7_DISABLED"));
  Serial.println(F("COMMANDS=ARM,DISARM,STATUS,HELP"));
}

void printTiming(uint32_t minValue, uint32_t maxValue, uint32_t sumValue,
                 uint16_t samples, const __FlashStringHelper *name) {
  Serial.print(name);
  Serial.print(F("_MIN_US="));
  if (!samples) Serial.println(F("NA"));
  else Serial.println(minValue);
  Serial.print(name);
  Serial.print(F("_MAX_US="));
  if (!samples) Serial.println(F("NA"));
  else Serial.println(maxValue);
  Serial.print(name);
  Serial.print(F("_AVG_US="));
  if (!samples) Serial.println(F("NA"));
  else Serial.println(sumValue / samples);
}

void finishTrain() {
  if (!trainActive || fallingPulses == 0) {
    resetTrain();
    return;
  }

  uint32_t durationUs = lastEdgeUs - trainStartUs;
  uint32_t valueCentavos = candidateCentavos(fallingPulses);
  Serial.println(F("BILL_EVENT:BEGIN"));
  Serial.print(F("RAW_PULSES="));
  Serial.println(fallingPulses);
  Serial.print(F("CANDIDATE_PHP="));
  if (valueCentavos) printMoney(valueCentavos);
  else Serial.print(F("UNKNOWN"));
  Serial.println();
  Serial.print(F("CANDIDATE_CENTAVOS="));
  Serial.println(valueCentavos);
  Serial.println(F("MAPPING_STATUS=UNVERIFIED_HYPOTHESIS_DO_NOT_CREDIT"));
  Serial.print(F("TRAIN_START_US="));
  Serial.println(trainStartUs);
  Serial.print(F("TRAIN_END_US="));
  Serial.println(lastEdgeUs);
  Serial.print(F("TRAIN_DURATION_US="));
  Serial.println(durationUs);
  printTiming(pulseWidthMinUs, pulseWidthMaxUs, pulseWidthSumUs,
              pulseWidthSamples, F("PULSE_WIDTH"));
  printTiming(gapMinUs, gapMaxUs, gapSumUs, gapSamples,
              F("INTERPULSE_GAP"));
  if (valueCentavos) {
    observedTotalCentavos += valueCentavos;
    Serial.print(F("OBSERVED_TOTAL_PHP="));
    printMoney(observedTotalCentavos);
    Serial.println();
  }
  Serial.println(F("ORDER_CREDIT=0"));
  Serial.println(F("BILL_EVENT:END"));
  resetTrain();
}

void processEdge(const EdgeEvent &event) {
  Serial.print(F("EDGE_LEVEL="));
  Serial.print(event.level ? F("HIGH") : F("LOW"));
  Serial.print(F(";TIMESTAMP_US="));
  Serial.println(event.timestampUs);

  lastEdgeUs = event.timestampUs;
  if (!event.level) {
    if (!trainActive) {
      resetTrain();
      trainActive = true;
      trainStartUs = event.timestampUs;
    }
    fallingPulses++;
    if (lastFallingUs) {
      uint32_t gap = event.timestampUs - lastFallingUs;
      if (gap < gapMinUs) gapMinUs = gap;
      if (gap > gapMaxUs) gapMaxUs = gap;
      gapSumUs += gap;
      gapSamples++;
    }
    lastFallingUs = event.timestampUs;
    pulseStartUs = event.timestampUs;
    pulseOpen = true;
  } else if (trainActive && pulseOpen) {
    uint32_t width = event.timestampUs - pulseStartUs;
    if (width < pulseWidthMinUs) pulseWidthMinUs = width;
    if (width > pulseWidthMaxUs) pulseWidthMaxUs = width;
    pulseWidthSumUs += width;
    pulseWidthSamples++;
    pulseOpen = false;
  }
}

void drainEdges() {
  if (takeOverflow()) {
    captureEnabled = false;
    resetTrain();
    Serial.println(F("FAULT=EDGE_RING_OVERFLOW;ARM_REQUIRED"));
    clearEdgeRing();
    return;
  }
  EdgeEvent event;
  while (popEdge(event)) processEdge(event);
  if (trainActive && (uint32_t)(micros() - lastEdgeUs) >= TRAIN_GAP_US) {
    finishTrain();
  }
}

void armObserver() {
  resetTrain();
  clearEdgeRing();
  captureEnabled = true;
  Serial.println(F("ARMED=1;OBSERVE_ONLY=1;ORDER_CREDIT=0"));
}

void disarmObserver() {
  captureEnabled = false;
  drainEdges();
  if (trainActive) finishTrain();
  clearEdgeRing();
  Serial.println(F("ARMED=0;OBSERVE_ONLY=1;ORDER_CREDIT=0"));
}

void processCommand() {
  commandBuffer[commandLength] = '\0';
  if (!strcmp(commandBuffer, "ARM")) armObserver();
  else if (!strcmp(commandBuffer, "DISARM")) disarmObserver();
  else if (!strcmp(commandBuffer, "STATUS")) printStatus();
  else if (!strcmp(commandBuffer, "HELP")) {
    Serial.println(F("COMMANDS=ARM,DISARM,STATUS,HELP"));
  } else if (commandLength > 0) {
    Serial.println(F("ERR=UNKNOWN_COMMAND"));
  }
  commandLength = 0;
}

void readCommands() {
  while (Serial.available() > 0) {
    char value = (char)Serial.read();
    if (value == '\n' || value == '\r') {
      processCommand();
    } else if (commandLength < sizeof(commandBuffer) - 1U) {
      commandBuffer[commandLength++] = value;
    } else {
      commandLength = 0;
      Serial.println(F("ERR=COMMAND_TOO_LONG"));
    }
  }
}

void setup() {
  // Observer safety: no inhibit drive, coin power off, PCA OE disabled.
  pinMode(PIN_METER, INPUT);
  pinMode(PIN_BILL_INHIBIT, INPUT);
  pinMode(PIN_COIN_POWER, OUTPUT);
  digitalWrite(PIN_COIN_POWER, LOW);
  pinMode(PIN_PCA_OE, OUTPUT);
  digitalWrite(PIN_PCA_OE, HIGH);

  Serial.begin(115200);
  attachInterrupt(digitalPinToInterrupt(PIN_METER), meterEdgeISR, CHANGE);
  delay(100);
  Serial.println(F("MENDO_BILL_OBSERVER:READY"));
  Serial.println(F("NO_ORDER_CREDIT_NO_INHIBIT_DRIVE_NO_SERVO"));
  printStatus();
  Serial.println(F("SEND=ARM_WHEN_READY_TO_CAPTURE_TB_METER"));
}

void loop() {
  readCommands();
  drainEdges();
}

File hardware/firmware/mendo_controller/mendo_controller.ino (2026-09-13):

/*
 * MendoVendo controller firmware.
 *
 * One source tree targets Arduino Uno and Mega. D0/D1 remain USB serial;
 * board selection changes only compile-time capacity. The host protocol is a
 * bounded ASCII frame with CRC16-CCITT. No Arduino String or JSON is used.
 *
 * Payment-only build: the measured D2/D3 pulse paths can credit a POS cash
 * session. Medicine motors remain compile-time disabled and this firmware
 * will reject every DISPENSE_ONE command.
 */

#include <Arduino.h>
#include <EEPROM.h>
#include <stdio.h>
#include <stdlib.h>
#include <string.h>
#include <Wire.h>

#if defined(ARDUINO_AVR_UNO)
static const uint8_t EEPROM_RING_SLOTS = 8;
static const uint8_t JOB_RING_SLOTS = 8;
#elif defined(ARDUINO_AVR_MEGA2560)
static const uint8_t EEPROM_RING_SLOTS = 24;
static const uint8_t JOB_RING_SLOTS = 24;
#else
static const uint8_t EEPROM_RING_SLOTS = 8;
static const uint8_t JOB_RING_SLOTS = 8;
#endif

static const uint8_t PIN_COIN = 2;          // INT0
static const uint8_t PIN_BILL = 3;          // INT1
static const uint8_t PIN_BILL_INHIBIT = 4;
static const uint8_t PIN_COIN_POWER = 5;
static const uint8_t PIN_CHUTE_RESERVED = 6;
static const uint8_t PIN_PCA_OE = 7;        // active low
static const uint8_t PIN_INTERLOCK = 8;
static const uint8_t PCA9685_ADDR = 0x40;
static const uint16_t FRAME_LIMIT = 240;
static const uint32_t HEARTBEAT_TIMEOUT_MS = 3000UL;

// ---------------------------------------------------------------------------
// Cash pulse discrimination.
//
// TB74 bill geometry is MEASURED, not assumed: 2026-08-03 bench captures gave
// LOW 50 ms, HIGH 100 ms, period 150 ms (Fast, 10-way SW4 = ON) for PHP
// 20/50/100 at 2/5/10 pulses. See
// docs/architecture/tb74-pulse-protocol-analysis.md.
//
// The same captures showed why raw edge counting cannot be used: one accepted
// PHP 50 note carried 12,871 raw interrupt edges around its 5 real pulses, a
// 2574:1 noise ratio. Counting raw edges would have credited PHP 128,710.
// Six rejected notes produced 23,064 raw edges and must credit exactly zero.
//
// Every pulse therefore has to survive three independent checks: a level
// stability (glitch) filter, a LOW-width window, and a minimum period. The
// fastest credit pulse anywhere in this device family is an 80 ms period, so
// anything quicker is provably not payment.
// ---------------------------------------------------------------------------
static const uint16_t BILL_GLITCH_MS     = 20;   // level must hold to count
static const uint16_t BILL_MIN_LOW_MS    = 25;   // measured 50 ms
static const uint16_t BILL_MAX_LOW_MS    = 400;
static const uint16_t BILL_MIN_PERIOD_MS = 80;   // family minimum
static const uint16_t BILL_GAP_MS        = 500;  // > 350 ms slow-mode gap
static const uint16_t BILL_MAX_PULSES    = 120;  // PHP 1000 = 100; cap runaway

// Allan coin acceptor, MEASURED 2026-08-04 after calibration:
//   LOW 69-77 ms (mostly 70), period 162-171 ms (mostly 170).
//   PHP 1 -> 1 pulse (6 samples), PHP 5 -> 5 pulses (3 samples).
// Slower than the bill line, so the filter can be just as strict.
//
// Coin value is LINEAR: 1 pulse = PHP 1 at every denomination. A rapid burst
// of coins merges into one train (110 pulses observed in a single 19 s train),
// so the host must scale by pulse count rather than look up a denomination.
// These are the exact loose discovery filters from the sketch used for the
// successful all-coin test. They accept the measured ~70 ms LOW / ~170 ms
// period while preserving the tested D2 behavior.
static const uint16_t COIN_GLITCH_MS     = 3;
static const uint16_t COIN_MIN_LOW_MS    = 4;
static const uint16_t COIN_MAX_LOW_MS    = 400;
static const uint16_t COIN_MIN_PERIOD_MS = 12;
static const uint16_t COIN_GAP_MS        = 400;
static const uint16_t COIN_MAX_PULSES    = 200;  // PHP 200 ceiling per train
static const uint16_t EEPROM_EVENT_BASE = 16;
static const uint16_t EEPROM_JOB_BASE = EEPROM_EVENT_BASE + EEPROM_RING_SLOTS * 8;
static const uint8_t EEPROM_JOB_RECORD_SIZE = 44;
static const uint8_t EEPROM_JOB_MARKER = 0xA6;
static const uint8_t JOB_STARTED = 1;
static const uint8_t JOB_DONE = 2;
// Cash and motion have separate gates. D2/D3 pulse acceptance is now enabled
// from the completed bench trials; actuator calibration is still absent, so
// no command can energize a medicine motor.
static const bool CASH_INPUTS_CONFIRMED = true;
static const bool MEDICINE_MOTORS_ENABLED = false;

// Source index: 0 = coin, 1 = bill. Parallel arrays rather than a struct so
// the Arduino 1.x auto-prototype pass cannot break the build.
static const uint8_t SRC_COIN = 0;
static const uint8_t SRC_BILL = 1;
const uint8_t  srcPin[2]       = {PIN_COIN, PIN_BILL};
const uint16_t srcGlitchMs[2]  = {COIN_GLITCH_MS, BILL_GLITCH_MS};
const uint16_t srcMinLowMs[2]  = {COIN_MIN_LOW_MS, BILL_MIN_LOW_MS};
const uint16_t srcMaxLowMs[2]  = {COIN_MAX_LOW_MS, BILL_MAX_LOW_MS};
const uint16_t srcMinPerMs[2]  = {COIN_MIN_PERIOD_MS, BILL_MIN_PERIOD_MS};
const uint16_t srcGapMs[2]     = {COIN_GAP_MS, BILL_GAP_MS};
const uint16_t srcMaxPulses[2] = {COIN_MAX_PULSES, BILL_MAX_PULSES};

// Raw edge counters are evidence only. They are never credited.
volatile uint16_t rawEdges[2] = {0, 0};

uint8_t  rawLevel[2], stableLevel[2], lowOpen[2], trainActive[2], suspect[2];
uint8_t  drainAfterStop[2] = {0, 0};
uint32_t lastRawChangeMs[2], trainStartMs[2], lastActivityMs[2];
uint32_t lowStartMs[2], prevLowStartMs[2];
uint16_t cleanPulses[2], rawAtTrainStart[2];

bool acceptorsEnabled = false;
bool controllerHealthy = false;
uint32_t lastHeartbeatMs = 0;
uint32_t bootSequence = 0;
uint16_t eventSequence = 0;
uint8_t jobRingIndex = 0;
char activeSession[40] = "";
char rxFrame[FRAME_LIMIT + 1];
uint16_t rxLength = 0;

struct SlotProfile {
  uint16_t positionA;
  uint16_t positionB;
  uint16_t travelMs;
  uint16_t dwellMs;
  uint16_t settleMs;
  uint16_t cooldownMs;
  const char *version;
};

SlotProfile profiles[10] = {
  {1500,1900,500,250,300,500,"v1-unmeasured"},
  {1500,1900,500,250,300,500,"v1-unmeasured"},
  {1500,1900,500,250,300,500,"v1-unmeasured"},
  {1500,1900,500,250,300,500,"v1-unmeasured"},
  {1500,1900,500,250,300,500,"v1-unmeasured"},
  {1500,1900,500,250,300,500,"v1-unmeasured"},
  {1500,1900,500,250,300,500,"v1-unmeasured"},
  {1500,1900,500,250,300,500,"v1-unmeasured"},
  {1500,1900,500,250,300,500,"v1-unmeasured"},
  {1500,1900,500,250,300,500,"v1-unmeasured"}
};

uint16_t crc16Ccitt(const uint8_t *data, uint16_t length) {
  uint16_t crc = 0xFFFF;
  for (uint16_t i = 0; i < length; i++) {
    crc ^= (uint16_t)data[i] << 8;
    for (uint8_t bit = 0; bit < 8; bit++) {
      crc = (crc & 0x8000) ? (uint16_t)((crc << 1) ^ 0x1021) : (uint16_t)(crc << 1);
    }
  }
  return crc;
}
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

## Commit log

2026-02-04 exp 1.0
    [Mendo-Datasets.xlsx]
2026-02-05 stable ver 1.0
    [Mendo-Datasets.xlsx]
2026-04-09 fixed lang-detection
    [test_results_20260409_180056.csv]
2026-07-22 Restore experiment-march-1 prototype
    Undo the accidental merge changes and conflict resolutions while preserving shared history. The resulting tree matches peer prototype commit 4a02b0f exactly.
    [duration_cases.csv, test_results_20260628_224357.csv, test_results_20260629_173125.csv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]
2026-07-22 some changes idk
    [duration_cases.csv, test_results_20260628_224357.csv, test_results_20260629_173125.csv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]
2026-07-27 Constrain dispensing to ten medicine slots
2026-08-12 Integrate payment hardware and complete thesis section
    [MAIN - container body and lid.stl, MAIN - container lid loose.stl, MAIN - magazine tube 180mm.stl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]
2026-09-27 Back up working Uno firmware (coin/bill/printer) after SSD loss
    Read-only avrdude dump of flash + EEPROM, verified against the chip; the
    printer-enabled controller source was lost and exists nowhere in git.
2026-09-27 Restore receipt printing and rebuild controller firmware
    The printer-enabled Uno firmware's source was lost with an SSD. Rebuild it
    from the repo's payment controller plus the protocol recovered from the
    backed-up image, and restore the host side of printing.
    - hardware/printer.py, receipt.py: idempotent PRINT_* job streaming with
    controller resync; 58 mm ESC/POS receipts with spaced rules and an ESC 7
    peak-heat limit (solid rules browned the shared-12 V printer out and
    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
2026-09-27 Let the daemon client outwait the controller's reply deadline
    A garbled controller reply makes the daemon wait up to its 2 s serial
    deadline; the 1.5 s socket timeout turned that into a client error while
    coins were being dropped on the bench.
2026-09-27 Timestamp the pulse-train log and add a cash_log bench tool
    Each logged coin/bill train now carries its controller start time, the log
    can be cleared before a run, and python -m hardware.cash_log prints it with
    wall-clock times so every coin maps to the moment it was dropped.
    Uno: 15,794 B flash, 635 B free SRAM; 300/300 command soak clean.
2026-09-27 Add cash_bench tool; record original-firmware coin A/B
    The lost firmware miscounts today's coins identically (N-1 per coin), so
    the coin fault is in the D2 wiring/signal, not the rebuilt firmware.
